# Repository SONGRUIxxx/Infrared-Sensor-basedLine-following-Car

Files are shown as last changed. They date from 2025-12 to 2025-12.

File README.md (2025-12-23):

# 综合设计与实践A综合实验设计报告

## 摘要
本项目以 STM32G030C8T6 单片机为控制核心，设计并实现了一款集成传感器系统、电机驱动与电源管理的双轮迷宫机器鼠，旨在完成前进、后退、变速、转向、避障及巡线等功能。硬件上，采用 TPS5430DDAR 将 6V 输入电压转换为 3.3V 系统电压，通过两片 TC118S 驱动双电机，8 个 ITR20001 红外传感器（4 个避障、4 个巡线）均以 ADC 方式采集模拟信号以提升感知精度；软件上基于 PD 算法计算电机转速差，结合定时器 PWM 输出与 DMA 传输实现高效控制。经调试，确定 KP=0.14、KD=0.1 为最优控制参数，机器鼠可在白色 KT 板（20~25mm 黑色胶带）场景中稳定巡线，且能及时响应避障需求，所有电路集成于单块定制 PCB，满足项目技术指标。

---

## 一．题意分析
### 1. 项目背景
本项目旨在基于STM32G030C8T6单片机为核心控制器，设计并制作一个能够自主在迷宫中导航的双轮智能机器鼠。该机器鼠需集成传感器系统、电机驱动、电源管理于一体，最终实现包括前进、后退、变速、原地转向、行进转向、避障、巡线在内的完整运动控制功能。

项目要求所有电子电路均集成于一块自主设计的PCB之上，严禁使用现成的功能模块，以全面考察硬件设计、嵌入式软件编程及系统集成能力。

### 2. 主要技术指标
1. 主控芯片：STM32G030C8T6单片机。
2. 电源系统：6V输入，TPS5430DDAR降压至3.3V。
3. 电机驱动：两片TC118S独立驱动双轮。
4. 传感器系统：8个ITR20001红外传感器（4避障+4巡线，ADC采集）。
5. PCB设计：所有电路集成于一块定制PCB。

---

## 二．原理分析
### 1. 运动控制原理
两轮差速模型，通过调节左右轮转速差实现转向。

### 2. 红外传感原理
ITR20001集成红外发射与接收，反射强度转为电压，ADC采集用于避障与巡线。

### 3. PWM调速原理
STM32定时器输出PWM，经TC118S调速，实现电机连续可调。

### 4. 方案比较
- 红外读取：GPIO（二元）vs ADC（模拟量），选ADC。
- 运动算法：PID vs PD，选PD（简化、抑制震荡）。

---

## 三．电路实现
### 1. 原理图
（详见原理图工程文件夹）

### 2. 局部分析
- 单片机模块：PA0~PA7为ADC，PA8~PA11为PWM，PD2为调试LED。
- 红外模块：发射端串330R，接收端上拉10K。
- 电源：R1=10K，R2=5.9K设定3.3V输出。
- 电机驱动：TC118S控制双轮。

---

## 四．软件算法
### 1. 代码流程
- 初始化：GPIO、DMA、ADC、TIM。
- 启动PWM、ADC DMA。
- 主循环：
  - 检查adc_ready。
  - 若有障碍物（adc[0~3]<阈值）：亮LED，调用bizhang()避障。
  - 否则：
    - 计算averange=adc[4]+adc[5]-adc[6]-adc[7]。
    - PD算法计算speed=KP*averange+KD*(averange-averange_last)。
    - 限幅后调用move(speed)。
  - 20ms周期。

### 2. 关键参数
- KP=0.14，KD=0.1。

---

## 五．测试方法、结果与分析
- 硬件确认、场景搭建。
- 调试顺序：先KP后KD，目标为无偏移巡线、平滑过弯、及时避障。
- 最终参数下，机器鼠在标准场景下表现稳定。

---

## 六．总结
- 硬件集成化，电路布局合理。
- 采用ADC采集提升感知精度。
- PD算法简化控制，满足动态性能。

---

## 附录A：电路原理图及PCB
详见原理图工程文件夹。

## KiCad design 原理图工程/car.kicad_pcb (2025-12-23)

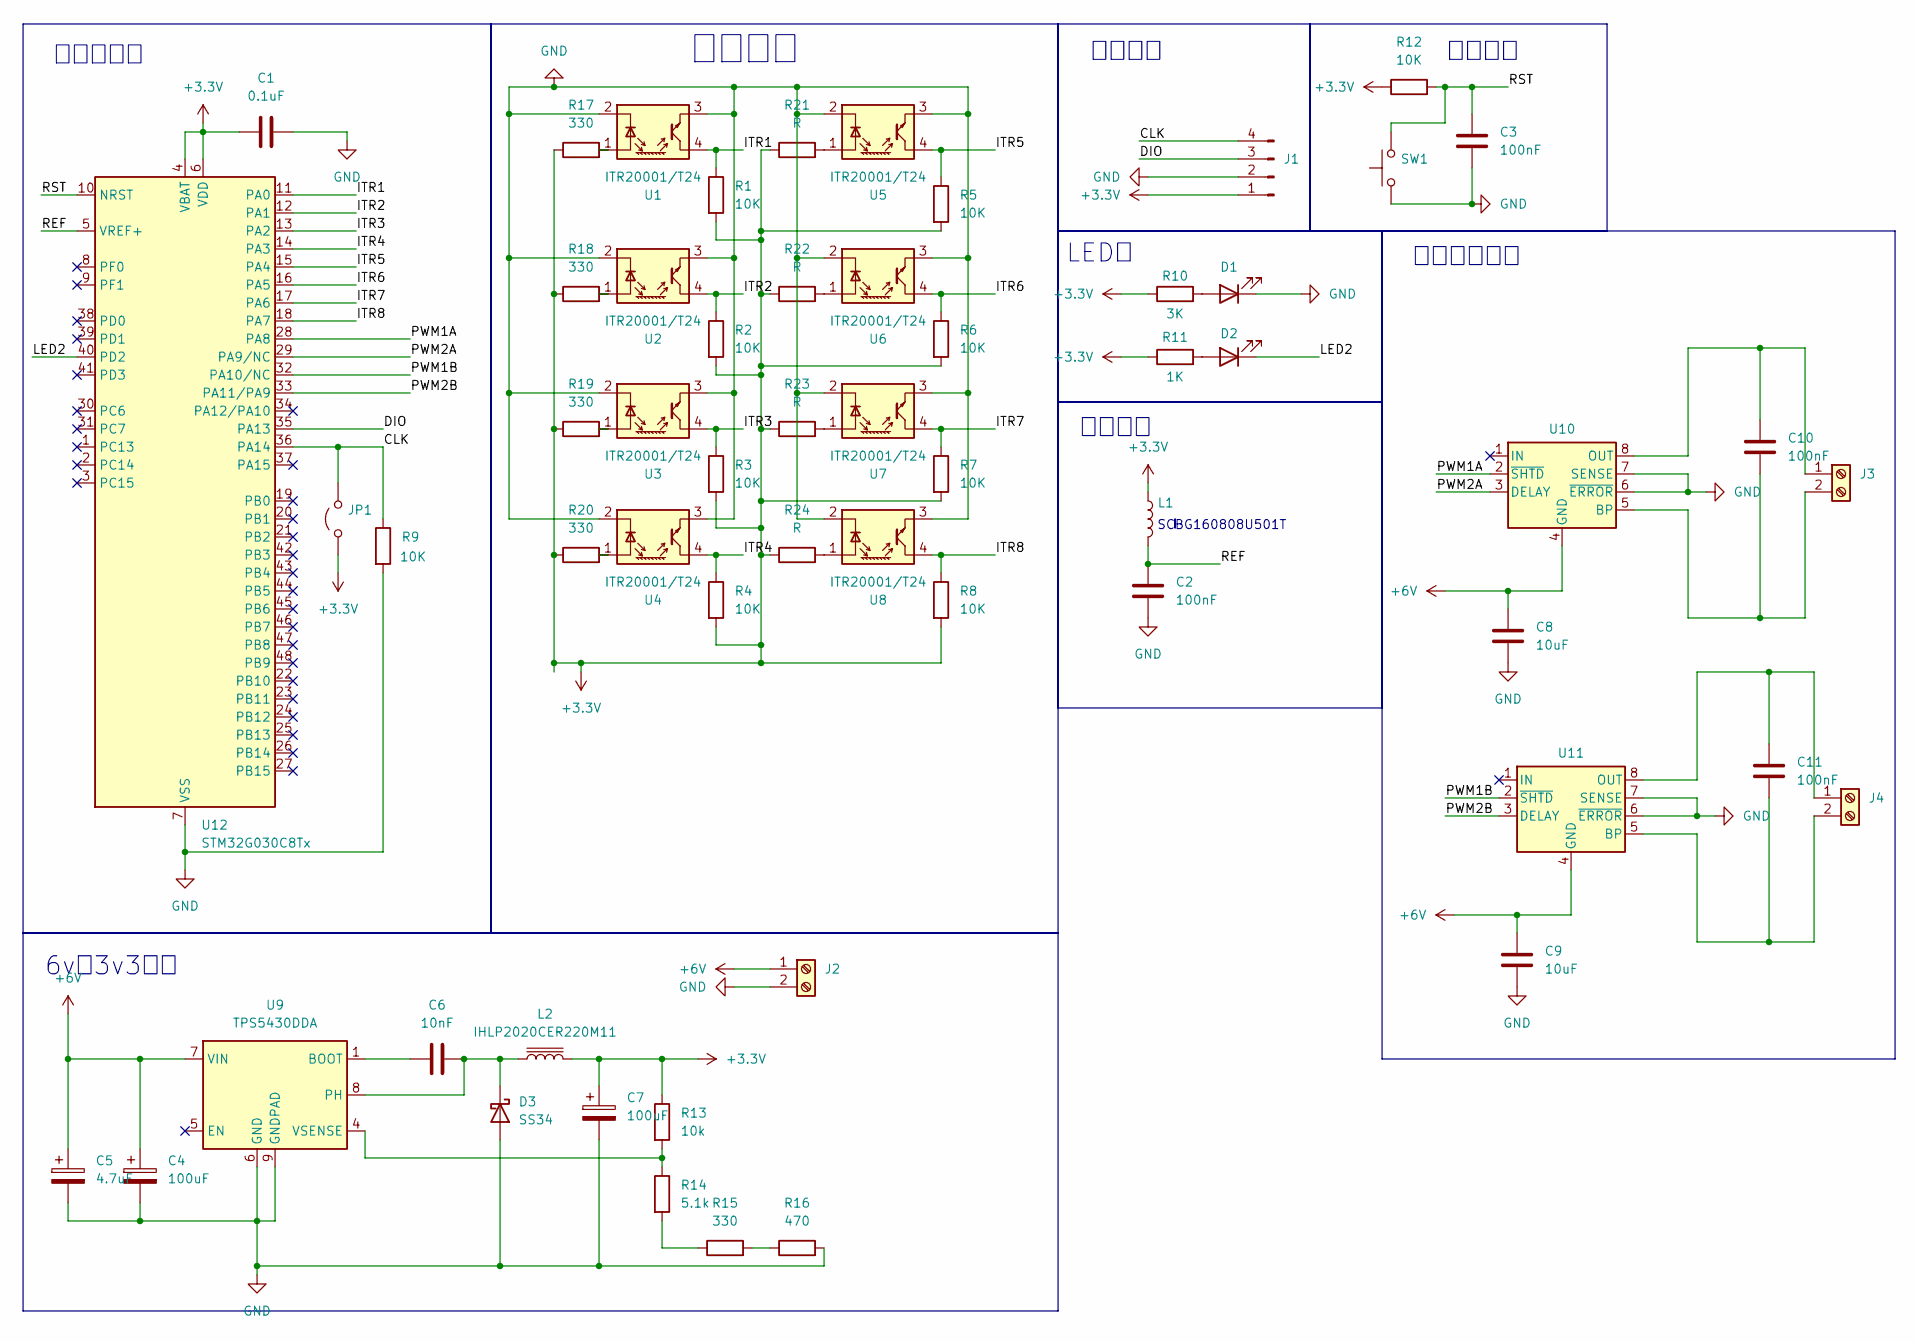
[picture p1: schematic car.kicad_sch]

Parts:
C1: 0.1uF; C_0805_2012Metric_Pad1.18x1.45mm_HandSolder
C2, C3, C10, C11: 100nF; C_0805_2012Metric_Pad1.18x1.45mm_HandSolder
C4, C7: 100uF; CP_Elec_6.3x5.4
C5: 4.7uF; CP_Elec_6.3x5.4
C6: 10nF; C_0805_2012Metric_Pad1.18x1.45mm_HandSolder
C8, C9: 10uF; C_0805_2012Metric_Pad1.18x1.45mm_HandSolder
D1: LED; LED_0805_2012Metric_Pad1.15x1.40mm_HandSolder
D2: LED; LED_0805_2012Metric
D3: SS34; D_SMA_Handsoldering
J1: Conn_01x04_Pin; FanPinHeader_1x04_P2.54mm_Vertical
J2, J3, J4: Screw_Terminal_01x02; Altech_AK100_1x02_P5.00mm
JP1: Jumper_2_Open; TestPoint_2Pads_Pitch2.54mm_Drill0.8mm
L1: L; L_0603_1608Metric_Pad1.05x0.95mm_HandSolder
L2: IHLP2020CER220M11; L_6.3x6.3_H3
R1, R2, R3, R4, R5, R6, R7, R8, R9, R12: 10K; R_0805_2012Metric_Pad1.20x1.40mm_HandSolder
R10: 3K; R_0805_2012Metric_Pad1.20x1.40mm_HandSolder
R11: 1K; R_0805_2012Metric_Pad1.20x1.40mm_HandSolder
R13: 10k; R_0805_2012Metric_Pad1.20x1.40mm_HandSolder
R14: 5.1k; R_0805_2012Metric_Pad1.20x1.40mm_HandSolder
R15, R17, R18, R19, R20: 330; R_0805_2012Metric_Pad1.20x1.40mm_HandSolder
R16: 470; R_0805_2012Metric_Pad1.20x1.40mm_HandSolder
R21, R22, R23, R24: R; R_0805_2012Metric_Pad1.20x1.40mm_HandSolder
SW1: SW_Push; SW_DIP_SPSTx01_Slide_6.7x4.1mm_W6.73mm_P2.54mm_LowProfile_J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
U1, U2, U3, U4, U5, U6, U7, U8: ITR20001/T24; Everlight_ITR20001
U9: TPS5430DDA; TI_SO-PowerPAD-8_ThermalVias
U10, U11: LP2988-5.0_SOIC8_VSSOP8; SOIC-8_3.9x4.9mm_P1.27mm
U12: STM32G030C8Tx; LQFP-48_7x7mm_P0.5mm

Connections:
+3.3V: C1.1, C7.1, J1.1, JP1.1 (A), L1.1, L2.2, R1.2, R2.2, R3.2, R4.2, R5.2, R6.2, R7.2, R8.2, R10.1, R11.1, R12.1, R13.1, R17.1, R18.1, R19.1, R20.1, R21.1, R22.1, R23.1, R24.1, U12.4 (VBAT), U12.6 (VDD)
+6V: C4.1, C5.1, C8.1, C9.1, J2.1, U9.7 (VIN), U10.4 (GND), U11.4 (GND)
/CLK: J1.4, JP1.2 (B), R9.1, U12.36 (PA14)
/DIO: J1.3, U12.35 (PA13)
/ITR1: R1.1, U1.4 (C), U12.11 (PA0)
/ITR2: R2.1, U2.4 (C), U12.12 (PA1)
/ITR3: R3.1, U3.4 (C), U12.13 (PA2)
/ITR4: R4.1, U4.4 (C), U12.14 (PA3)
/ITR5: R5.1, U5.4 (C), U12.15 (PA4)
/ITR6: R6.1, U6.4 (C), U12.16 (PA5)
/ITR7: R7.1, U7.4 (C), U12.17 (PA6)
/ITR8: R8.1, U8.4 (C), U12.18 (PA7)
/LED2: D2.1 (K), U12.40 (PD2)
/PWM1A: U10.2 (~SHTD), U12.28 (PA8)
/PWM1B: U11.2 (~SHTD), U12.32 (PA10/NC)
/PWM2A: U10.3 (DELAY), U12.29 (PA9/NC)
/PWM2B: U11.3 (DELAY), U12.33 (PA11/PA9)
/REF: C2.1, L1.2, U12.5 (VREF+)
/RST: C3.1, R12.2, SW1.2, U12.10 (NRST)
GND: C1.2, C2.2, C3.2, C4.2, C5.2, C7.2, C8.2, C9.2, D1.1 (K), D3.2 (A), J1.2, J2.2, R9.2, R16.2, SW1.1, U1.2 (K), U1.3 (E), U2.2 (K), U2.3 (E), U3.2 (K), U3.3 (E), U4.2 (K), U4.3 (E), U5.2 (K), U5.3 (E), U6.2 (K), U6.3 (E), U7.2 (K), U7.3 (E), U8.2 (K), U8.3 (E), U9.6 (GND), U9.9 (GNDPAD), U10.6 (~ERROR), U10.7 (SENSE), U11.6 (~ERROR), U11.7 (SENSE), U12.7 (VSS)
unnamed: D1.2 (A), R10.2
unnamed: D2.2 (A), R11.2
unnamed: C6.2, D3.1 (K), L2.1, U9.8 (PH)
unnamed: C10.1, J3.1, U10.8 (OUT)
unnamed: C10.2, J3.2, U10.5 (BP)
unnamed: C11.1, J4.1, U11.8 (OUT)
unnamed: C11.2, J4.2, U11.5 (BP)
unnamed: R14.2, R15.1
unnamed: R15.2, R16.1
unnamed: R17.2, U1.1 (A)
unnamed: R18.2, U2.1 (A)
unnamed: R19.2, U3.1 (A)
unnamed: R20.2, U4.1 (A)
unnamed: R21.2, U5.1 (A)
unnamed: R22.2, U6.1 (A)
unnamed: R23.2, U7.1 (A)
unnamed: R24.2, U8.1 (A)
unnamed: C6.1, U9.1 (BOOT)
unnamed: R13.2, R14.1, U9.4 (VSENSE)

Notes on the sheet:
单片机模块
电机驱动系统
6v转3v3电路
LED灯
红外模块
复位按键
烧录接口
SCBG160808U501T
参考电压

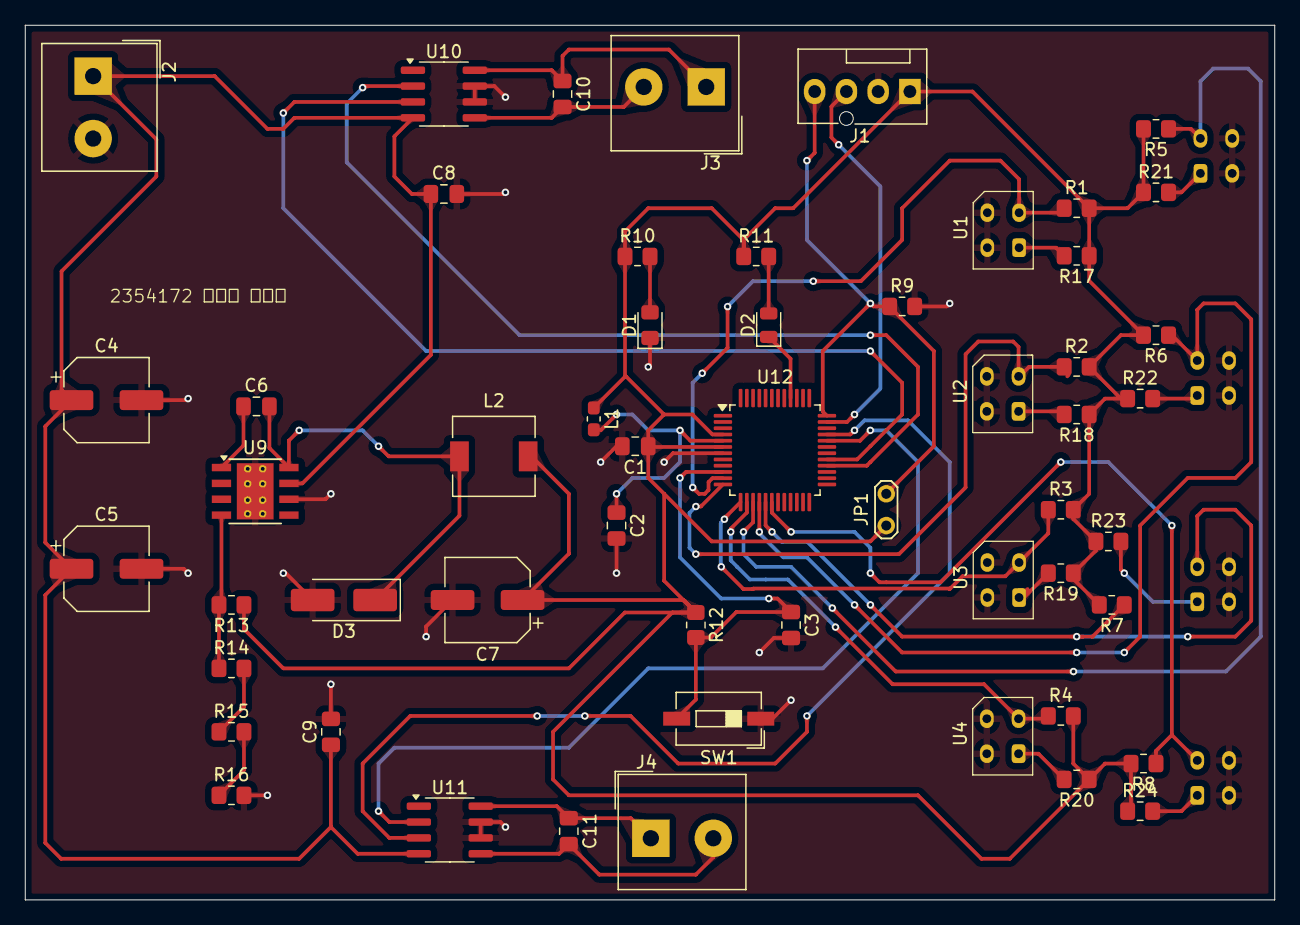
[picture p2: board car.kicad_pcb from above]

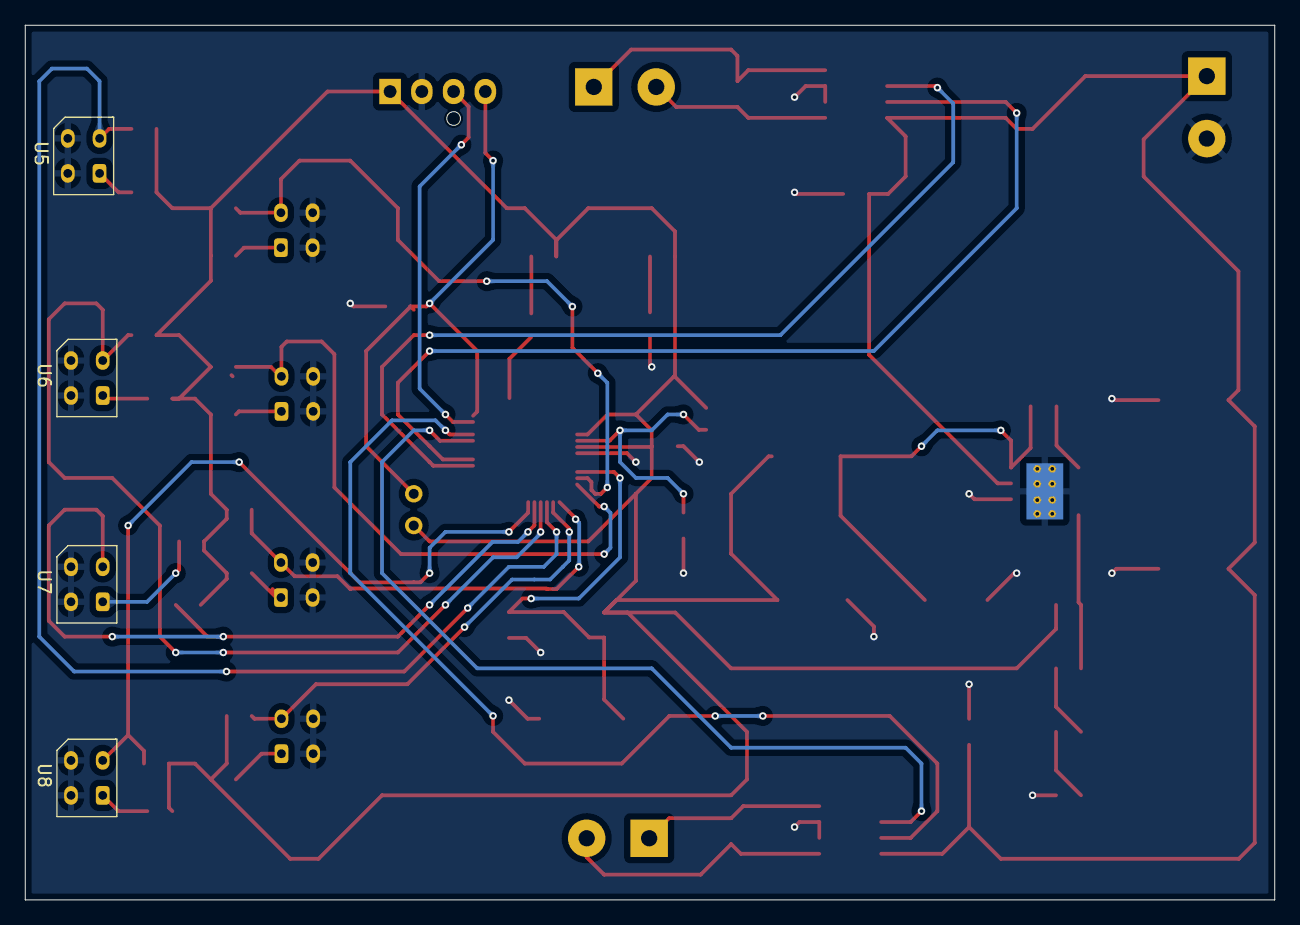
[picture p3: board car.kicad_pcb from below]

Board: 2 copper layers, 100.0 x 70.0 mm, 58 parts (4 on the bottom side), 39 nets.

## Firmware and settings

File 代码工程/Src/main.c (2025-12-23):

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
/* Includes ------------------------------------------------------------------*/
#include "main.h"
#include "adc.h"
#include "dma.h"
#include "tim.h"
#include "gpio.h"

/* USER CODE BEGIN Includes */
#define speed_basic 300
#define obstacle_threshold 3600
#define KP 0.14
#define KD 0.1
uint16_t adc[8] = {0};
uint8_t adc_ready = 0;

/* USER CODE END Includes */

/* USER CODE BEGIN PTD */
void HAL_ADC_ConvCpltCallback(ADC_HandleTypeDef *hadc) {    
    adc_ready = 1; 
		
}
void pwm_init()
{
HAL_TIM_PWM_Start(&htim1, TIM_CHANNEL_1);
HAL_TIM_PWM_Start(&htim1, TIM_CHANNEL_2);
HAL_TIM_PWM_Start(&htim1, TIM_CHANNEL_3);
HAL_TIM_PWM_Start(&htim1, TIM_CHANNEL_4);
}
void move(int speed)
{
	__HAL_TIM_SET_COMPARE(&htim1, TIM_CHANNEL_1, speed_basic-speed);
	__HAL_TIM_SET_COMPARE(&htim1, TIM_CHANNEL_2, 0);
	__HAL_TIM_SET_COMPARE(&htim1, TIM_CHANNEL_3, speed_basic+speed);
	__HAL_TIM_SET_COMPARE(&htim1, TIM_CHANNEL_4, 0);
}

void back()
{
	__HAL_TIM_SET_COMPARE(&htim1, TIM_CHANNEL_1, 0);
	__HAL_TIM_SET_COMPARE(&htim1, TIM_CHANNEL_2, 600);
	__HAL_TIM_SET_COMPARE(&htim1, TIM_CHANNEL_3, 0);
	__HAL_TIM_SET_COMPARE(&htim1, TIM_CHANNEL_4, 600);
}

void stop()
{
	__HAL_TIM_SET_COMPARE(&htim1, TIM_CHANNEL_1, 0);
	__HAL_TIM_SET_COMPARE(&htim1, TIM_CHANNEL_2, 0);
	__HAL_TIM_SET_COMPARE(&htim1, TIM_CHANNEL_3, 0);
	__HAL_TIM_SET_COMPARE(&htim1, TIM_CHANNEL_4, 0);
}

void bizhang()
{
	__HAL_TIM_SET_COMPARE(&htim1, TIM_CHANNEL_1, 900);
	__HAL_TIM_SET_COMPARE(&htim1, TIM_CHANNEL_2, 0);
	__HAL_TIM_SET_COMPARE(&htim1, TIM_CHANNEL_3, 100);
	__HAL_TIM_SET_COMPARE(&htim1, TIM_CHANNEL_4, 0);
}


/* USER CODE END PTD */


void SystemClock_Config(void);
/**
  * @brief  The application entry point.
  * @retval int
  */
int main(void)
{

  /* MCU Configuration--------------------------------------------------------*/

  /* Reset of all peripherals, Initializes the Flash interface and the Systick. */
  HAL_Init();

  /* Configure the system clock */
  SystemClock_Config();

  /* Initialize all configured peripherals */
  MX_GPIO_Init();
  MX_DMA_Init();
  MX_ADC1_Init();
  MX_TIM1_Init();
  /* USER CODE BEGIN 2 */
int averange=0;
int averange_last=0;
int speed=0;
pwm_init();
HAL_ADC_Start_DMA(&hadc1, (uint32_t*)adc, 8); 
  /* USER CODE END 2 */

  /* Infinite loop */
  /* USER CODE BEGIN WHILE */
  while (1)
  {	
    /* USER CODE END WHILE */

    /* USER CODE BEGIN 3 */
		//0-1 1-
    if(adc_ready)
		{
			if(adc[0]<obstacle_threshold||adc[1]<obstacle_threshold||adc[2]<obstacle_threshold||adc[3]<obstacle_threshold)
			{
				
				HAL_GPIO_WritePin(GPIOD, GPIO_PIN_2, GPIO_PIN_RESET);
				bizhang();
				HAL_Delay(500);
				while(1)
				{
					stop();
				}
		   
			}
			else
			{
			
			 averange=adc[4]+adc[5]-adc[6]-adc[7];
			 speed=KP*averange+KD*(averange-averange_last);
			 averange_last=averange;
			if(speed>300)
			{
				speed=300;
			}
			if(speed<-300)
			{
				speed=-300;
			}
			 move(speed);			 			 
		  }
			adc_ready=0;
		}
		else
		{
		}
		HAL_Delay(20);
 }
  /* USER CODE END 3 */
}

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


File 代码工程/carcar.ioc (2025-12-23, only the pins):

Mcu.UserName=STM32G030C8Tx
PA0.Signal=SharedAnalog_PA0
PA1.Signal=SharedAnalog_PA1
PA10.Signal=S_TIM1_CH3
PA13.Signal=SYS_SWDIO
PA14-BOOT0.Signal=SYS_SWCLK
PA2.Signal=SharedAnalog_PA2
PA3.Signal=SharedAnalog_PA3
PA4.Signal=SharedAnalog_PA4
PA5.Signal=SharedAnalog_PA5
PA6.Signal=SharedAnalog_PA6
PA7.Signal=SharedAnalog_PA7
PA8.Signal=S_TIM1_CH1
PA9.Signal=S_TIM1_CH2
PD2.Signal=GPIO_Output

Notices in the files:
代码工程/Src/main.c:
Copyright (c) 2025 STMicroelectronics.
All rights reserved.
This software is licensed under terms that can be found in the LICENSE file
